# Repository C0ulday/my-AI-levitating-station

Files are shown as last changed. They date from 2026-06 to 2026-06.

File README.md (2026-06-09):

# [ ◕‿◕ ] Floating AI Cube

A small AI companion cube that floats under its base, shows a face on a round screen, listens, and talks back.

**Inspirations:** floating globe / moon lamps · desktop AI companions

> Journey: Idea → Prototyping → Hardware → PCB → 3D Design → Maglev station → Code

---

## ✦ The Idea

A **62×62×62 mm** cube that:

- **floats** below an arm-mounted electromagnet (suspension-type maglev)
- runs a **cloud AI pipeline**: voice in → ESP32 → WiFi → speech-to-text → LLM → text-to-speech → speaker
- shows a **face / clock / images** on a round display
- switches **mode when rotated** (IMU) and knows when it's **docked** (Hall)

> **Constraint #1 : weight.** A home-built coil lifts ~100–150 g all-in, so the whole cube is built for the lightest possible mass: thin walls, low infill, minimal components.

Idea sketch

---

## ✦ Architecture

The smart "brain" (wake word → STT → LLM → TTS) lives in the cloud. The ESP32 only captures, displays, and orchestrates.

```
Voice ──► I2S mic ──► ESP32 ──► (WiFi) ──► STT ──► LLM ──► TTS
                        │
                        ├──► round screen (face / clock / image)
                        ├──► I2S amp ──► speaker
                        ├──► MPU6050   (rotation → next mode)
                        ├──► Hall A3144 (docked / removed)
                        └──► Bluetooth ◄── phone audio
```

Maglev station (home-built, *suspension* type — the cube hangs under an arm):

```
Linear Hall ──► Arduino UNO (PID) ──► MOSFET ──► coil (12 V)
      ▲                                            │
      └──────────── field of the N52 magnet ◄──────┘  (in the top of the cube)
```

> ⚠️ **Two different Hall sensors:** a **digital A3144** inside the cube (docked / removed), and a **linear** Hall in the station (position feedback for the PID loop).

---

## ✦ Prototyping

Breadboard first to validate the whole "floats + detects rotation/dock + speaks" loop. Build order is deliberate: **cube electronics + software first**, then the **maglev station second** — only once the cube is finished and weighed.

---

## ✦ Hardware

### Cube
| Component | Model | Specs | Notes |
|---|---|---|---|
| MCU | ESP32 NodeMCU (CH340) | classic BT | BT classic needed for phone audio |
| Display | GC9A01 1.28" round IPS SPI | 240×240 | 3.3 V |
| Amp | MAX98357A (I2S) | audio out | **5 V** |
| Speaker | 40 mm | 4 Ω, 3 W | |
| Mic | INMP441 (I2S) | voice in | 3.3 V |
| IMU | MPU6050 (I2C) | rotation → mode | mount perfectly flat |
| Hall | A3144 (digital) | dock / removal | 5 V supply, output pulled to 3.3 V |
| Battery | LiPo 3.7 V 1000 mAh (803040) | energy | |
| Charge | TP4056 USB-C (protected) | recharge | ~0.5 A recommended |
| Boost | MT3608 | 3.7 V → 5 V | **set to ~5.1 V before connecting** |
| Levitated magnet | N52 15×5×2 mm (×1–5) | maglev | stacked for more force, centered in the top |
| Inserts | brass | **M2.5** heat-set | |
| Connectors | JST PH 1.25 | harness | with a loop of slack |

### Maglev station (phase 2)
| Component | Role |
|---|---|
| Coil (enamelled wire + iron/ferrite core) | electromagnet |
| **Linear** Hall (SS49E / A1302 / DRV5055) | position feedback |
| Logic-level MOSFET (IRLZ44N) + flyback diode | power stage |
| Arduino UNO | PID loop |
| 12 V 2–3 A supply | drives the coil |

> Station shape: ~140 mm ballasted base, ~200–220 mm total height, coil support in **PETG** (heat). The base is mains-powered; only the cube is wireless.

> **Power rule (cube):** on the protected TP4056 the load draws from **OUT+** (not BAT); pre-adjust the MT3608 to **~5.1 V** before plugging anything in.

---

## ✦ PCB (KiCad)

This is the project where the **custom PCB** lives. Workflow learned the hard way: don't design the enclosure until the board is real.

```
breadboard ──► freeze schematic (KiCad) ──► route PCB ──► export STEP ──► import into FreeCAD ──► design the cube around the real board
```

---

## ✦ 3D Design

FreeCAD for the cube and the station. Cube priorities: the **levitation magnet dead-centered** at the top, **symmetric mass** for a stable float, a screen window, a speaker grille, a mic port (kept away from the speaker), the Hall sensor facing the base, an access panel for SD/charge, and thin walls to save weight.

3D Design

---

## ✦ Sourcing

| Supplier | What |
|---|---|
| Kubii.fr | round display, microSD |
| Gotronic.fr | MAX98357A, INMP441, MPU6050, A3144, TP4056, MT3608, speaker, JST, M2.5 inserts |
| Amazon.fr | LiPo (fastest/safest here), fast restocks |
| AliExpress | cheapest modules + the levitation coil hardware (slow shipping) |

> Order the **levitation coil first** — it sets the weight budget, and everything else is sized around what it can lift.

---

## 💻 Code

C / C++ (Arduino framework on the ESP32). The ESP32 handles capture, display, audio I2S, the IMU/Hall mode state machine, and the WiFi calls to the cloud AI; the station runs a separate **PID** loop on the Arduino UNO.

To do — firmware once the breadboard core is validated.

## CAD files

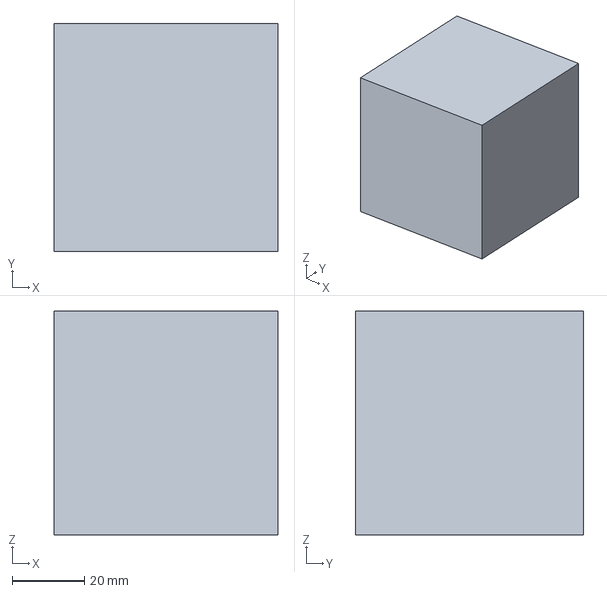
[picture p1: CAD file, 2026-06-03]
Design/design3D.FCStd
62.0 x 63.0 x 62.0 mm

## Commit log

2026-06-03 design first
    [design3D.FCStd]
2026-06-09 Fix formatting of Hall sensors warning in README
